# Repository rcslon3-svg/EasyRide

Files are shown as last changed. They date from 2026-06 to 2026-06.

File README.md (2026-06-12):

# EasyRide - www.smartmoto.asia
EasyRide - proximity Bluetooth BLE ignition switch for motorcycle, based on Arduino board Supermini or Nice!Nano nRF52840.

# Video

How to easy ride https://youtu.be/58KhOKnijgE

# EasyRide BLE Ignition Switch — Open Source

Keyless Bluetooth ignition system for motorcycles and scooters.  
A Bluetooth-based start authorization unit wired into the motorbike ignition circuit. Your phone in the pocket replaces the physical key for daily riding. Turn ignition on by stock button (starter or killswitch).

Open hardware, firmware and documentation.

Compatible with motorbikes that have electric starter and NO factory keyless/keyfob or chip-key immobilizer.

Phone: Android and iOS with Bluetooth Low Energy support.

Not compatible with motorbikes that have factory keyless/keyfob or a chip-key immobilizer.

---

## What it does

- Unlocks the ignition when your phone with Bluetooth BLE enabled is nearby — no app required
- PIN code fallback via the starter button — if the phone is unavailable
- Standby current under 2 mA 
- Auto-locks after you walk 5–7 metres away

---

## How to use

Behavior will be changed by TYPE of your motorcycle and connection method.
1. Motorcycle witn killswitch. Ignition ON/OFF by killswitch.
2. Motorcycle only with starter button. Ignition ON/OFF by starter button. OFF - with brake pressed. Start - when brake released.
3. Scooter (variator transmission). Ignition ON/OFF by starter button. OFF - when brake released. Start - when brake pressed.

4. If you ride off without your phone — the engine will not stall. Warning beeps at 5, 15 and 30 sec. Once ignition OFF - enter your PIN.

### Every day

1. Approach the scooter → system detects your phone → ignition unlocks
2. Double-press the starter button (or press killswitch on - depended of connection and setting) → beep + ignition turns on
3. Start the engine as usual (check your type - brake appied or not).
4. Stop → double-press the starter (check your type - brake appied or not) → ignition turns off
5. Walk away → after 5–7 metres the system locks automatically.

### Specification

Supply voltage (nominal)	12 V

Supply voltage (operating)	5-24 V

Supply voltage (absolute max.)	30 V

Current on IGN output	7 A continuous, 10 A max

Current through ST1, ST2 contacts	0.5 A max

Standby current consumption	1.2 mA

Operating temperature	-20 to +80 degrees C

Dimensions	45 × 45 × 20 mm

Weight	25 g

### PIN code (phone dead or unavailable)

1. Hold the button (starter or killswitch - see above) for 3 sec until the beep → PIN entry mode active
2. Enter each digit by pressing the button N times, wait 1 sec → confirmation beep, next digit
3. After the last digit hold the button for 3 sec → ignition turns on
4. Wrong code → low beep, 15 sec lockout, retry
5. Mistake mid-entry → do nothing for 15 sec → low beep, auto-reset, try again

---

## Configuration

BLE device name, pairing code (6 digits) and PIN code (3 digits) are set by the user in the code before compiling and flashing.

---

## Pairing a new phone

1. Move the old phone out of range or turn it off
2. Enable Bluetooth on the new phone
3. Find the device name in the scan list and tap to pair
4. Enter the 6-digit pairing code

Only one phone can be paired at a time.

---

## How to get it.

You can assemble and program it yourself or buy it here https://www.smartmoto.asia 

---

## Repository structure

```
/
├── hardware/      # Schematics, PCB, BOM
├── firmware/      # Firmware source code
├── bootloader/    # BLE bootloader
├── docs/          # Picture, wiring guide, how to connect to motorcycle
└── README.md
```

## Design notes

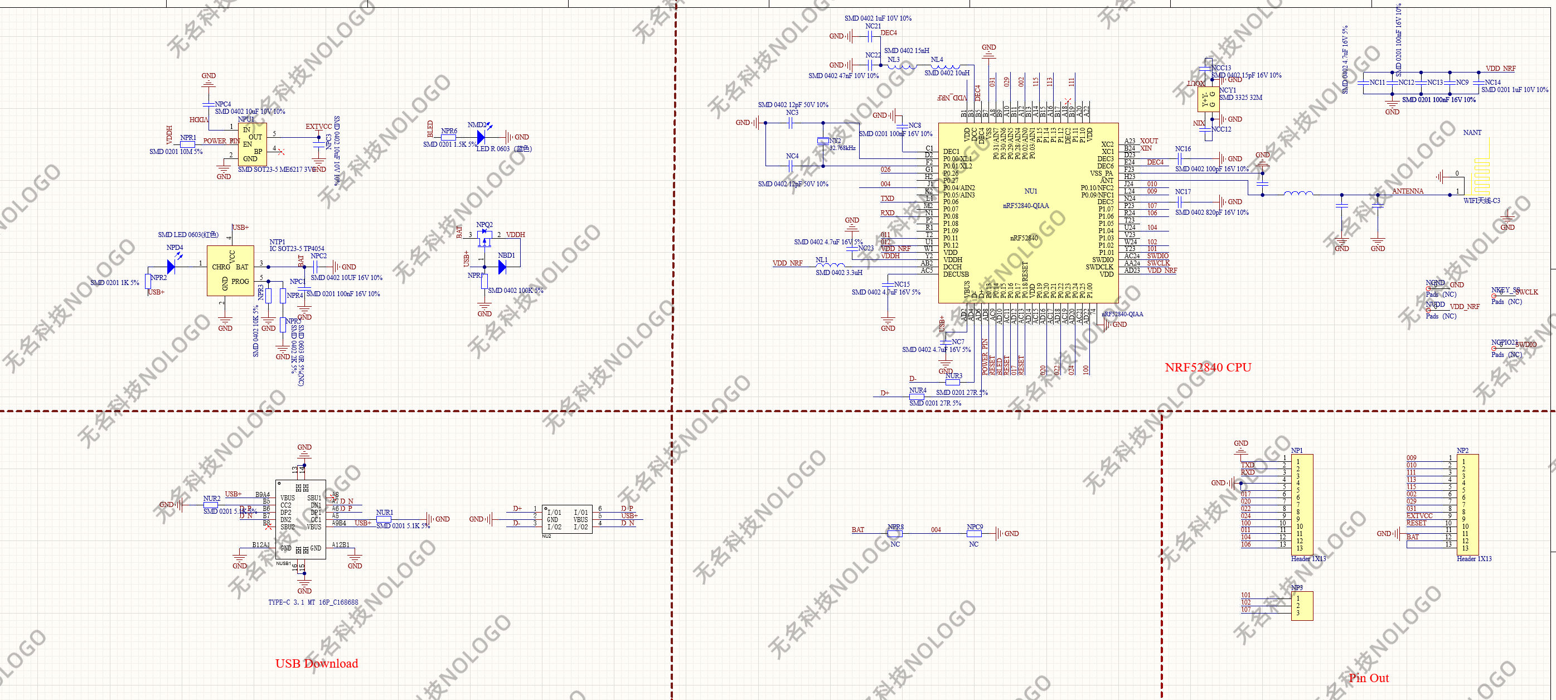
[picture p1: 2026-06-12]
hardware/supermini_nrf52840_schematic.jpg

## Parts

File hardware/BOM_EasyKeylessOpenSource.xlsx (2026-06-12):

Comment | Description | Designator | Footprint | Quantity | Part Number
220uF 63V | -55℃~+105℃ 10.2mm 10mm 2000hrs@105℃ 292mA@120Hz 330uF 50V ±20% SMD,D10xL10.2mm Aluminum Electrolytic Capacitors - SMD ROHS | C1 | SMD_AL_10x12.6_(Size code F12) | 1 | 189RV0038
0603 10uF 25V | 10uF, 25V, ±10%, X5R, 0603 | C2 | CAP0603 | 1 | CL10A106MA8NRNC
0603 470pF 50V | 470pF, 50V, ±5%, X7R, 0603 | C3, C4, C5, C6 | CAP0603 | 4 | 0603B471K500NT
0603 1uF 50V | 1uF, 50V, ±10%, X7R, 0603 | C7 | CAP0603 | 1 | CL10A105KB8NNNC
0603 100k 1% | 0.1W, 75V, 100ppm/Cel, 1% | R1, R3, R7, R8, R9, R14, R15, R19, R24, R25 | RES0603 | 10 | 0603WAF1003T5E
0603 20k 1% | 0.1W, 75V, 100ppm/Cel, 1% | R2, R4, R10, R11, R20, R21, R22 | RES0603 | 7 | 0603WAF2002T5E
0603 680 1% | 0.1W, 75V, 100ppm/Cel, 1% | R5, R6, R31 | RES0603 | 3 | 0603WAF6800T5E
0603 10k 1% | 0.1W, 75V, 100ppm/Cel, 1% | R12 | RES0603 | 1 | 0603WAF1002T5E
0603 4.7k 1% | 0.1W, 75V, 100ppm/Cel, 1% | R13, R16, R27, R28, R30 | RES0603 | 5 | 0603WAF4701T5E
0603 2.2k 1% | 0.1W, 75V, 100ppm/Cel, 1% | R17 | RES0603 | 1 | 0603WAF2201T5E
0603 240 1% | 0.1W, 75V, 100ppm/Cel, 1% | R18 | RES0603 | 1 | 0603WAF2400T5E
SE8633 | LDO, 200mA, 60V, 0.3V Dropout, SOT23-3 | U1 | SOT-23-3 | 1 | SE8633X2-HF
GAQY212G1S | -40℃~+85℃ 1.2V 1.3A 1.5kV 130mΩ 1ms 450mW 50mA 600us 60V AC,DC One set normally open: 2A (SPST - normally open) SOP-4 Solid State Relays (MOS Output) ROHS | U2 | SOP-4 | 1 | GAQY212G1S
SMAJ30CA | TVS Diode, 400W, 30V V(RWM), Bidirectional, 1 Element, Silicon, DO-214AC | VD1, VD3, VD4, VD8, VD9 | DO-214AC (SMA) | 5 | SMAJ30CA
1N5819WS | Rectifier Diode, 1 Phase, 1 Element, 0.15A, 75V V(RRM), Silicon, SOD-323 | VD2, VD7, VD10 | SOD-323 | 3 | 1N5819WS
BZT52C15S-7-F | 15V 200mW SOD-323 | VD5, VD6 | SOD-323 | 2 | BZT52C15S-7-F
SMAJ24CA | TVS Diode, 400W, 30V V(RWM), Bidirectional, 1 Element, Silicon, DO-214AC | VD11, VD12 | DO-214AC (SMA) | 2 | SMAJ24CA
MMBT5551 | NPN 0.5A 45V | VT1, VT2, VT6, VT7, VT8, VT10 | SOT-23-3N | 6 | MMBT5551
SP40P03NK | P-Channel 100A 60V 3 mOhm PDFN5x6 | VT3, VT5 | PPAK5*6-8L_(PDFN5*6) | 2 | SP40P03NK
MMBT5401 | PNP 0.5A 45V | VT11 | SOT-23-3N | 1 | MMBT5401
PLS-2 (DS1021-1x2) | Single Row Pin Header pitch 2.54mm, male | X1, X2, X6 | PLS-2 (DS1021-1x2) | 3 | DS1021-1x2SF11-B
PLS-3 (DS1021-1x3) | Single Row Pin Header pitch 2.54mm, male | X3, X4 | PLS-3 (DS1021-1X3) | 2 | DS1021-1x3SF11-B
DLL-5569-8AW | -35℃~+105℃ 16P 2 2x4P 300V 4.2mm 5.5mm 8 9A Brass Mini-Fit(MX 4.2) PA66 Right Angle Tin Transparent UL94V-0 Push-Pull,P=4.2mm Wire To Board Connector ROHS | X5 | DLL-5569-8AW | 1 | DLL-5569-8AW

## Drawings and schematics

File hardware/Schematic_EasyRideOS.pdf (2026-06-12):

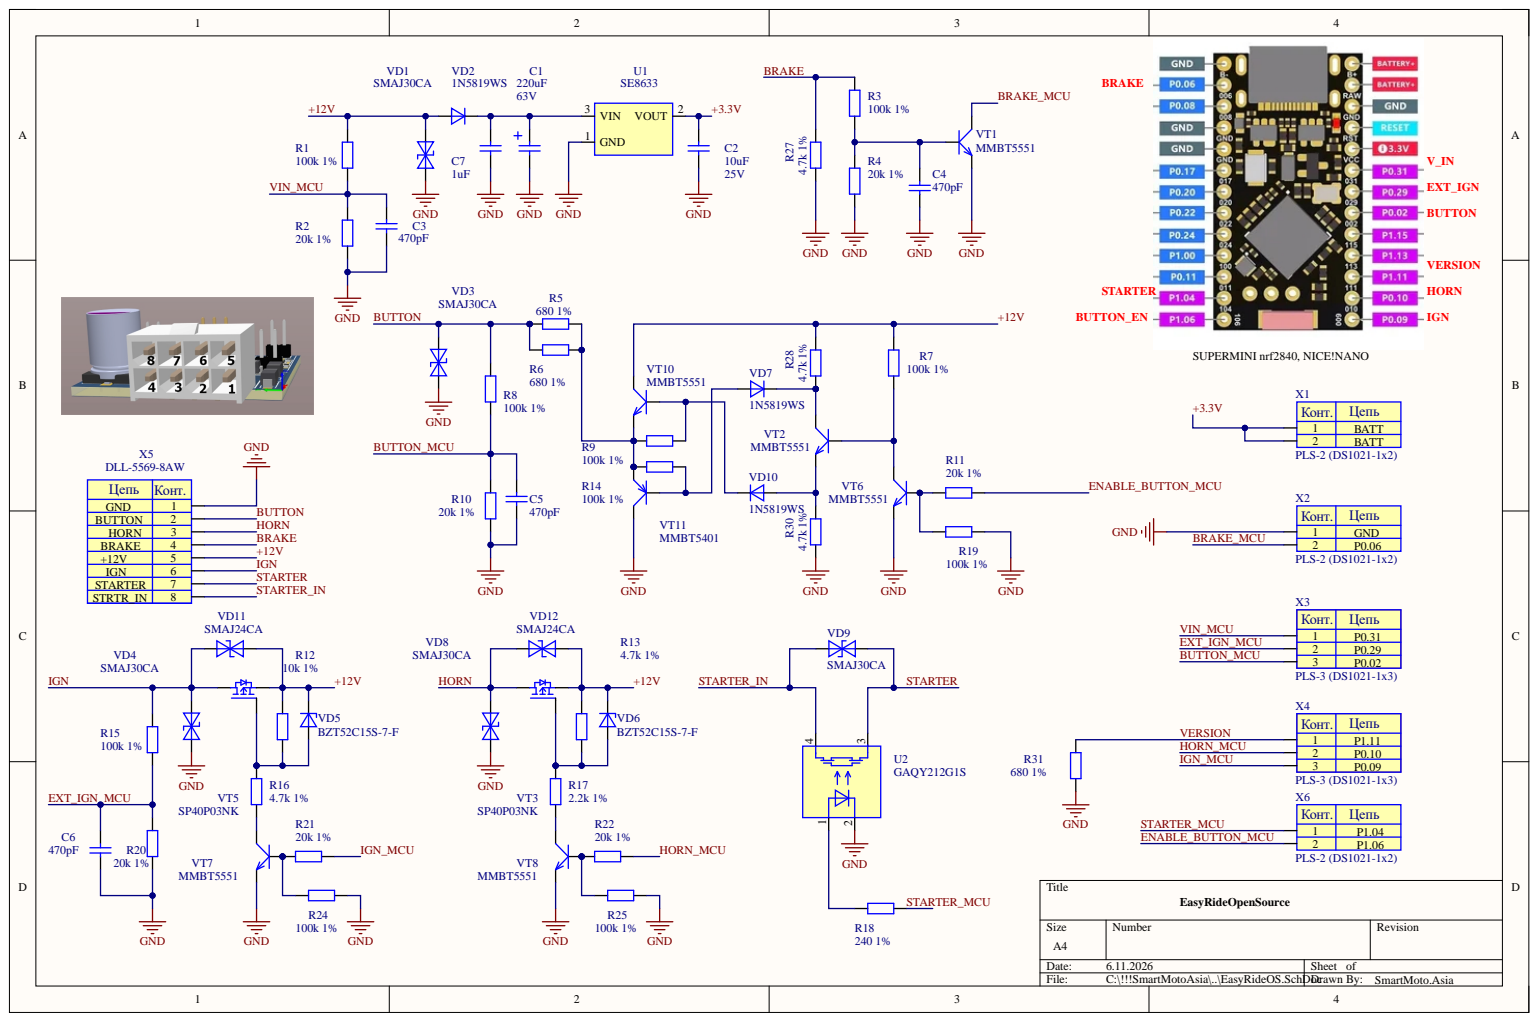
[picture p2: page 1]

Конт. | Цепь
1 | BATT
2 | BATT

Цепь | Конт.
GND | 1
BUTTON | 2

+12V | 5
IGN | 6
STARTER | 7
STRTR_IN | 8

1 | P0.31
2 | P0.29
3 | P0.02

1 | P1.11
2 | P0.10
3 | P0.09

1 | P1.04
2 | P1.06
